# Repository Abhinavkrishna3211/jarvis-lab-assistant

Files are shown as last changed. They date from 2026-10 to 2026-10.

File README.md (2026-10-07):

# JARVIS: an offline lab assistant on the Arduino UNO Q

A voice assistant for an open IoT-club lab. Ask it where a tool is and a laser marks the hook; ask for a
component and the LED under its box lights; lend and return hardware by voice and it keeps the log.
Everything runs on the board: no internet, no cloud account.

## How it works

```
mic -> "Hey Jarvis" (App Lab keyword spotting, always listening) -> "Good evening, sir."
    -> record until you pause (6 s max) -> whisper.cpp tiny.en -> fuzzy candidate match (about 10 items)
    -> keyword rules; if they give up on a known item, Gemma 3 1B (App Lab llama.cpp runner,
       JSON-schema constrained) -> validator -> SQLite
    -> Piper reply and Bridge calls to the STM32: point / laser / box_led / ring_state
```

The model never touches facts it could invent. It returns one short JSON action; code checks the intent, the
item against the inventory, quantity, borrower and due date, and does all date and stock arithmetic.
Loans and returns are read back and need a spoken "yes" or a tap on the dashboard before anything is saved.

Why keyword rules first: on the UNO Q, Gemma 3 1B takes about 28 s per request and scored lower than the
rules on our 60 test commands (it also invents items when someone makes small talk). So the rules answer
instantly, and Gemma only gets the requests they can't parse but that mention an item or a use of one.
JARVIS says "One moment, sir" before those. The numbers are in [docs/measurements.md](docs/measurements.md).

| Layer | Where | Files |
|---|---|---|
| Intent parsing | Linux (MPU) | `python/jarvis/llm.py`, `python/jarvis/matcher.py` |
| Validation, dates, loans | Linux | `python/jarvis/validate.py`, `python/jarvis/dates.py`, `python/jarvis/db.py` |
| Dialogue / persona | Linux | `python/jarvis/dialogue.py`, `python/jarvis/engine.py` |
| Voice I/O | Linux | `python/jarvis/voice.py` |
| Laser, LEDs, servos | STM32 (MCU) | `sketch/sketch.ino` |
| Dashboard | Linux | `assets/index.html`, `python/jarvis/dashboard.py` |
| App Lab entry point | Linux | `python/main.py`, `app.yaml` |

## Our Edge Impulse models

We trained both of these ourselves in Edge Impulse. The projects are public:

| Model | What it does | Project |
|---|---|---|
| Vision | Object detection on the tool wall, trained on photos of the lab's wall | [studio.edgeimpulse.com/public/1128889](https://studio.edgeimpulse.com/public/1128889/live) |
| Keyword | The "Hey Jarvis" wake word (classes JARVIS and NOISE, about 10 ms per window), runs on the board | [studio.edgeimpulse.com/public/1128798](https://studio.edgeimpulse.com/public/1128798/live) |

The keyword model is exported as a Linux AARCH64 `.eim`, copied to `/home/arduino/.arduino-bricks/ei-models/hey-jarvis.eim`
on the board, and selected with `EI_KEYWORD_SPOTTING_MODEL` in `app.yaml`. The `.eim` files aren't committed.

## Try it without hardware

```bash
pip install -r requirements-dev.txt
python -m pytest -q              # parsing, validation and loan-logic tests
python eval/run_eval.py          # 60-command keyword baseline
python python/jarvis/app.py      # typed input, simulated hardware, dashboard on http://127.0.0.1:8000
```

The simulator uses the keyword rules alone unless you pass `--llm-url` pointing at any OpenAI-compatible
server running Gemma 3 1B; then it uses the same rules-then-Gemma parser as the board.

## Install on an Arduino UNO Q

JARVIS is a standard Arduino App Lab app. Full step-by-step instructions, including wiring, are in
[docs/tutorial.md](docs/tutorial.md). The short version:

1. Download this repository as a zip.
2. In App Lab: **My Apps → Import**, pick the zip. (Or on the board:
   `arduino-app-cli app import jarvis.zip`.)
3. Open the app. In the **Large Language Model** brick, make sure **Gemma 3 1B** is selected and
   downloaded (722 MB).
4. Plug a USB mic (and a USB speaker, or pair a Bluetooth one: see the tutorial) into a powered USB-C hub, then press **Run**. The first start downloads
   the whisper and Piper models (136 MB). After that it runs offline.
5. Say **"Hey Jarvis"** (our Edge Impulse model, see above). Without the `.eim`, remove the variable in
   `app.yaml`, set `JARVIS_WAKE_WORD=hey_arduino`, and say **"Hey Arduino"** instead.
   The dashboard is at `http://<board-ip>:7000`.

Hook angles and LED indexes in `python/jarvis/db.py` are placeholders until you calibrate in the real lab
(`docs/wiring.md`).

## Safety and privacy

- Laser: a small keychain red pointer module, driven well below its rated current, auto-off after 10 s (enforced in both Python and firmware), aimed only at the wall. Its optical power was not measured with an instrument, so the post reports it as an unverified low-power pointer.
- Camera faces the tool wall and boxes, never people. It only looks for tools (our Edge Impulse model).
- The loan log stores first names only and never leaves the board.

## Evaluation

`eval/commands.json` holds 60 labelled requests. `eval/run_eval.py` scores the keyword baseline, and with
`--gemma <url>` the Gemma pipeline, counting a request correct only if intent, item, quantity and borrower all
match after validation. On the UNO Q, with typed input:

| Parser | Correct | Time per command |
|---|---|---|
| Keyword rules | 41/60 | median 0.23 s |
| Gemma 3 1B alone | 21–22/60 | median about 28 s |
| **Hybrid (what JARVIS uses)** | **45/60** | median 0.35 s; Gemma asked on 18 of 60 |

We chose the hybrid rule after seeing Gemma's answers on these same 60 commands, so its score is optimistic.
Spoken tests with real people are still to do. All measured numbers, and how each was measured, are in
[docs/measurements.md](docs/measurements.md).

## License

MIT

## Changes after the submission deadline

The deadline was 5 Oct 2026, 12:29 PM IST. The submitted version is commit `d8290db` (pushed 5 Oct 2026,
12:24 PM IST). After the submission the code was polished and improved, and a proper schematic was added
([docs/schematic/jarvis.pdf](docs/schematic/jarvis.pdf)), which had been left out of the earlier commits.
These commits were made after the deadline:

| Commit | Time (IST) | Change |
|---|---|---|
| `bb17d30` | 6 Oct 2026, 00:34 | Two-servo pan-tilt head with camera aiming, laser moved to D7, KiCad schematic |
| `aa3d326` | 6 Oct 2026, 00:36 | Wiring guide for the pan-tilt head; README edit |
| `9af7c13` | 6 Oct 2026, 00:37 | First version of this note |
| last commit | 7 Oct 2026, 16:18 | This list; AGENTS.md intro edit |

On 6 Oct the branch was force-pushed by mistake (00:38 and 00:42 IST); on 7 Oct 2026, 16:18 IST it was restored, so every
commit up to `d8290db` is exactly as submitted.

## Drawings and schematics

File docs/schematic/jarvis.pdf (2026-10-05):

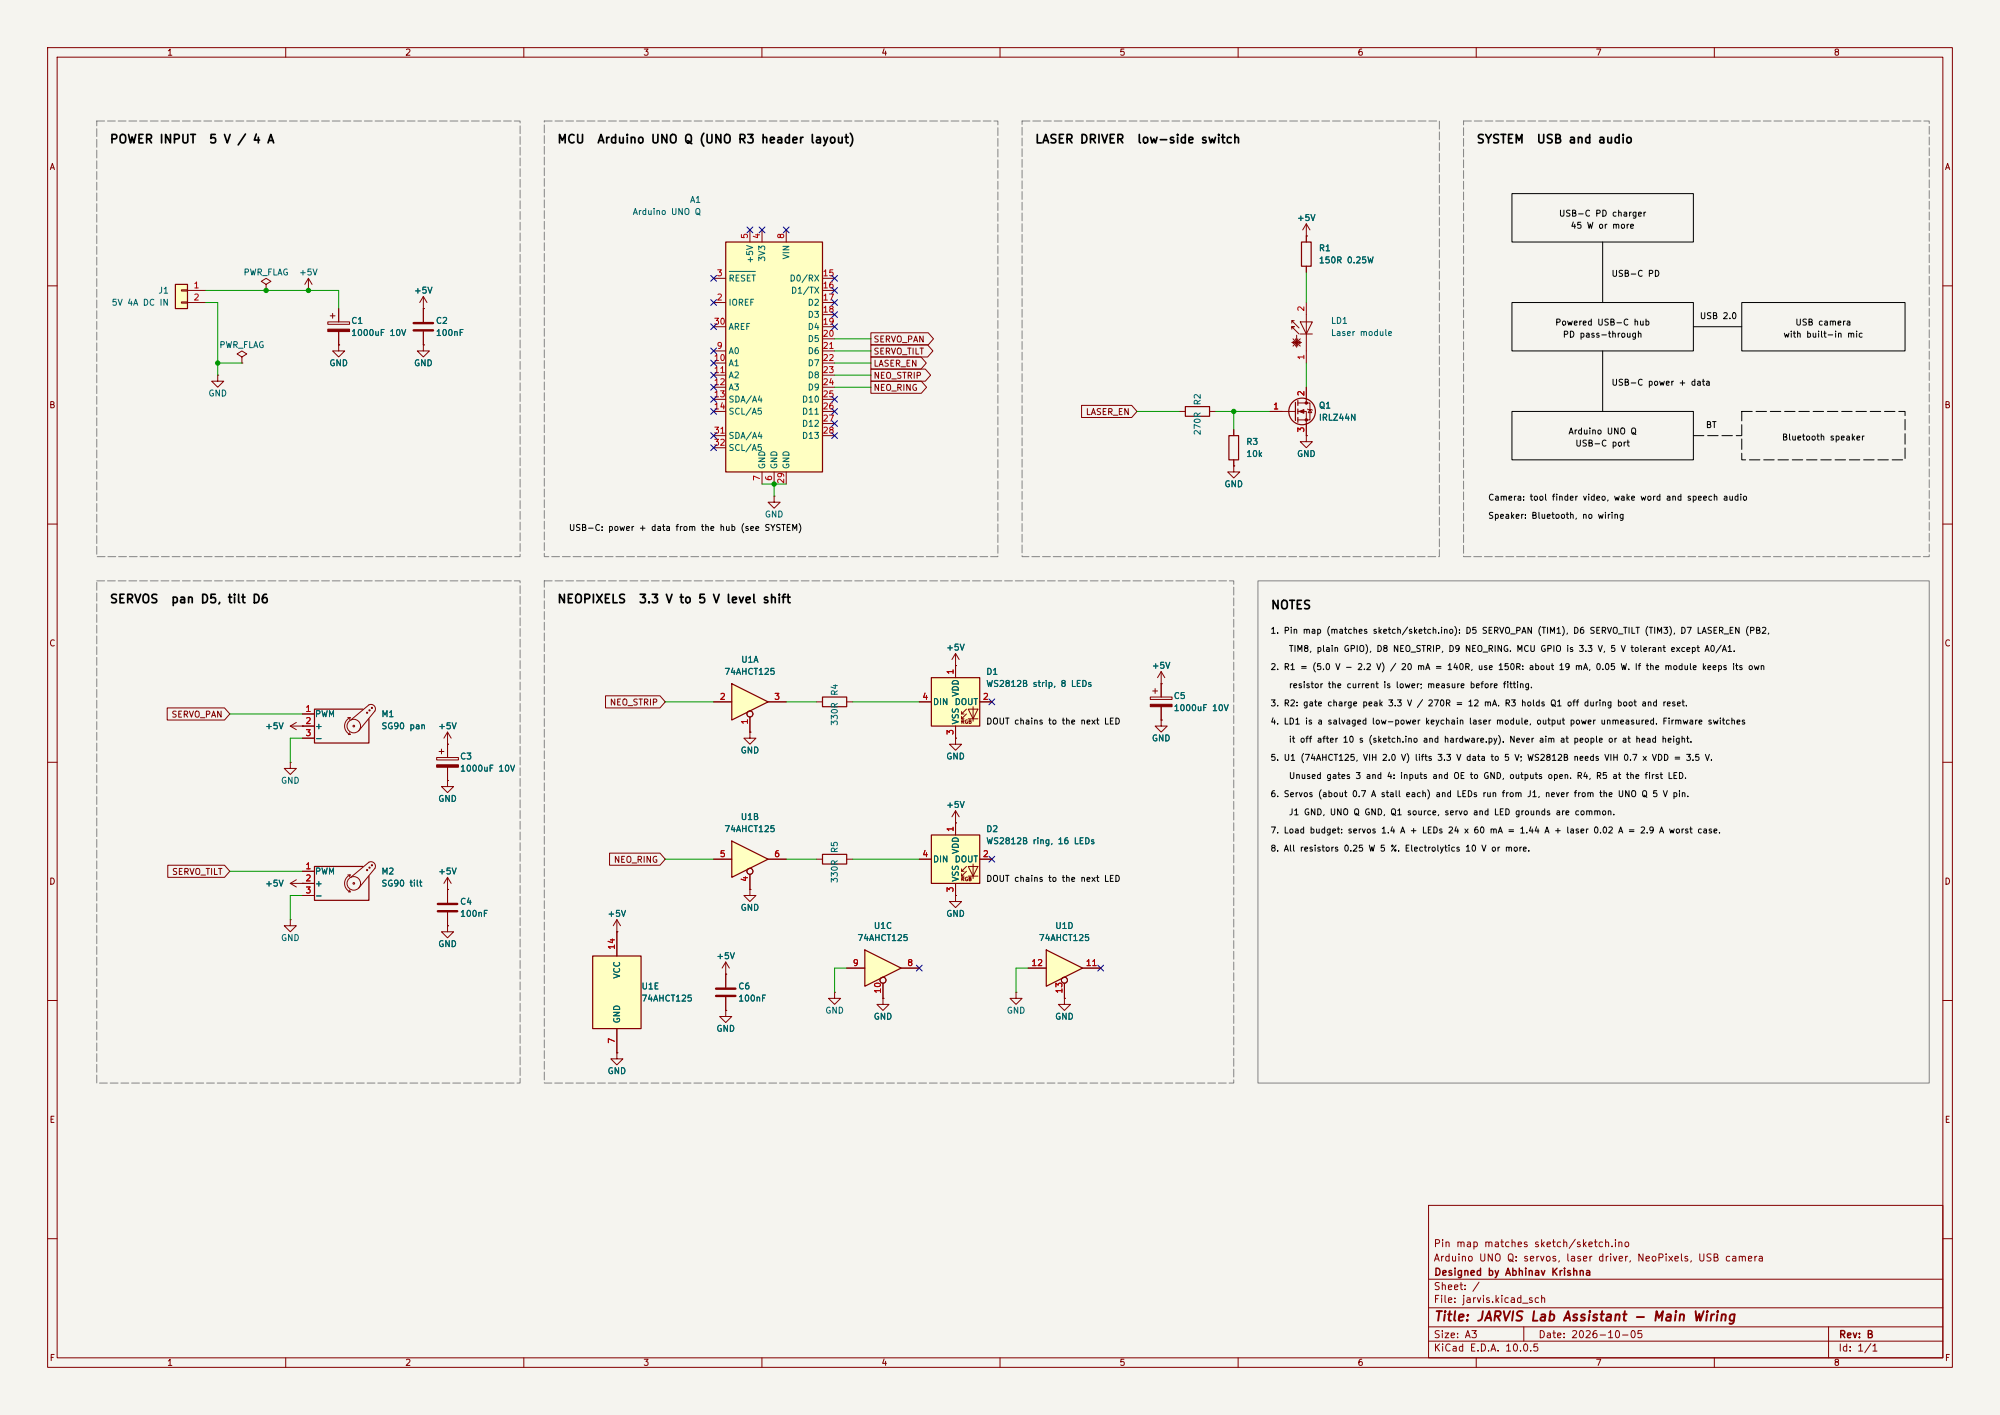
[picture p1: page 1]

Arduino UNO Q LASER DRIVER low-side switch

SYSTEM USB and audio

USB-C power + data USB-C PD USB-C: power + data from the hub (see SYSTEM)

TIM8, plain GPIO), D8 NEO_STRIP, D9 NEO_RING. MCU GPIO is 3.3 V, 5 V tolerant except A0/A1. resistor the current is lower; measure before fitting. 3. R2: gate charge peak 3.3 V / 270R = 12 mA. R3 holds Q1 off during boot and reset. 1. Pin map (matches sketch/sketch.ino): D5 SERVO_PAN (TIM1), D6 SERVO_TILT (TIM3), D7 LASER_EN (PB2, 2. R1 = (5.0 V - 2.2 V) / 20 mA = 140R, use 150R: about 19 mA, 0.05 W. If the module keeps its own 4. LD1 is a salvaged low-power keychain laser module, output power unmeasured. Firmware switches 5. U1 (74AHCT125, VIH 2.0 V) lifts 3.3 V data to 5 V; WS2812B needs VIH 0.7 x VDD = 3.5 V. 7. Load budget: servos 1.4 A + LEDs 24 x 60 mA = 1.44 A + laser 0.02 A = 2.9 A worst case. 8. All resistors 0.25 W 5 %. Electrolytics 10 V or more.

DOUT chains to the next LED

3 DIN 4 D2WS2812B ring, 16 LEDs +5V GND
RGB VDD

Designed by Abhinav Krishna
Sheet: /
File: jarvis.kicad_sch
Title: JARVIS Lab Assistant - Main Wiring

Size: A3 | Rev: B | F Date: 2026-10-05
KiCad E.D.A. 10.0.5 | Id: 1/1

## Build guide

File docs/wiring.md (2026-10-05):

# Wiring and calibration

| Part | Connects to | Notes |
|---|---|---|
| Pan servo (SG90, bottom of the pan-tilt head) | STM32 PWM pin D5 | Swings left and right; detached after each move to stop jitter |
| Laser module (from a keychain pointer, cells removed) | D7 through a logic-level MOSFET (IRLZ44N): 270 R gate, 10k gate pulldown | 5 V rail through a 150 R series resistor, about 19 mA; firmware off-timer of 10 s |
| Tilt servo (SG90, top of the head, carries the laser) | D6 | Swings up and down (lower angle = higher dot) |
| WS2812 strip (one LED per box) | D8 through a 74AHCT125 (5 V) and 330 R | 8 LEDs by default |
| NeoPixel ring (status) | D9 through the same 74AHCT125 and 330 R | 16 LEDs |
| Servos, LEDs power | Separate 5 V supply | Shared ground with the UNO Q |
| Mic, speaker | USB sound card on a powered USB-C hub | Hub also feeds the USB camera |

Full schematic with the resistor calculations: [schematic/jarvis.pdf](schematic/jarvis.pdf) (KiCad source `schematic/jarvis.kicad_sch`, regenerate with `python docs/schematic/make_sch.py docs/schematic/jarvis.kicad_sch`).

Pins are set at the top of `sketch/sketch.ino`. Servo 1.3.0 and Adafruit NeoPixel 1.15.5 compile on the
`arduino:zephyr` 1.0.0 core (verified 4 Oct 2026; versions pinned in `sketch/sketch.yaml`).

## Pan-tilt head

A standard two-SG90 pan-tilt bracket (the two-piece plastic kit).

1. Before fitting the horns, centre both servos: `POST /api/point?pan=90&tilt=90` (laser stays off).
2. Pan servo in the base, horn up; the lower bracket screws onto that horn.
3. Tilt servo in the upper bracket; the laser module sits on the tilt platform, beam parallel to it,
   held with a zip tie or hot glue so it can't slip (a slipped laser silently breaks the calibration).
4. Mount the head at bench height facing the tool wall, with no walkway between head and wall. The beam
   should only ever reach the wall, never head height.
5. Fix the camera next to the head, not on it, so the camera's view and the head don't move together.
   Moving either one means calibrating again.
6. Servo power comes from the separate 5 V supply (about 0.7 A stall each), never from the UNO Q's 5 V pin.

## Calibrating hooks

Two steps, both from the dashboard host (`http://<board-ip>:7000`):

1. **Hook angles by hand.** For each hook, jog until the dot sits on it:
   `POST /api/point?pan=90&tilt=65&laser=1` (the laser still switches off after 10 s). Write each
   hook's `(pan, tilt)` into `HOOK_ANGLES` in `python/jarvis/db.py` and restart the app. Record the miss
   distance in centimetres for the evaluation.
2. **Camera fit.** Hang every tool on its own hook, then `POST /api/calibrate`. The camera finds each tool
   with the vision model and fits pixel position to `(pan, tilt)`; the result is saved to `data/vision.json`.
   It needs 2 or more tools seen. Hooks in one column only teach tilt; hooks spread across the wall teach
   both axes. Every aim is clamped to the box the calibrated hooks span, so a bad detection can't swing
   the laser off the wall.

Without `vision.json` (or with the camera unplugged), JARVIS points at each tool's home hook.

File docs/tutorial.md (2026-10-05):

# Build your own JARVIS: step by step

This guide takes you from an empty Arduino UNO Q to a lab assistant that answers to its wake word, marks
tools with a laser, and keeps the lending log by voice. The steps are the ones we actually followed; any
step not yet run on real hardware is marked **(not yet verified)**.

Numbers quoted here come from [measurements.md](measurements.md).

## What you need

| Part | Why | Status on our bench |
|---|---|---|
| Arduino UNO Q (2 GB is enough) | Runs everything: Linux for speech and the model, STM32 for the hardware | ✅ |
| Powered USB-C hub with USB-A ports | The UNO Q has one USB-C port; mic, speaker and power share it | to buy |
| USB microphone (a USB webcam's mic works) | Voice in | ✅ Arducam camera mic |
| Speaker: USB, or a Bluetooth speaker (see Step 5) | Voice out | ✅ Bluetooth |
| SG90 servos × 2 and a pan-tilt bracket | Aim the laser | 1 of 2 servos |
| Laser module from a keychain pointer (cells removed), plus a logic-level MOSFET (IRLZ44N) | Marks the hook on the tool wall | ✅ both |
| WS2812 LED strip | One LED under each component box | to buy |
| 16-LED NeoPixel ring | Status: idle, listening, thinking, speaking, error | ✅ |
| Separate 5 V supply | Servos and LEDs draw too much for the board | |

You also need a computer with [Arduino App Lab](https://www.arduino.cc/en/software/) and an
internet connection **for the first start only** (to download the models).

## Step 1: Prepare the board

1. Connect the UNO Q to Wi-Fi through App Lab's first-run setup.
2. Check you have room. Open the board's terminal (App Lab, or `ssh arduino@<board-ip>`) and run:
   ```bash
   free -m      # we had 1249–1277 MB available out of 1740 MB
   df -h /      # we had 1.1 GB free out of 9.8 GB: too little
   ```
   JARVIS needs about 2.5 GB of free disk on the first start: the Gemma model (722 MB), the
   llama.cpp and keyword-spotting runner images, and the speech models (136 MB). If you're short, export
   any old apps you want to keep (`arduino-app-cli app export <app> backup.zip --include-data`), then delete
   them in App Lab and remove Docker images you no longer use (`docker images`, then `docker rmi <image>`).

## Step 2: Import the app

1. Download this repository as a zip (GitHub: **Code → Download ZIP**).
2. In App Lab, import the zip as a new app. You can do the same from the board's terminal:
   ```bash
   arduino-app-cli app import jarvis.zip
   ```
   Verified on our UNO Q 2GB.

What's inside, and why App Lab needs each piece:

| Path | Role |
|---|---|
| `app.yaml` | Declares the app and its three bricks: `arduino:llm` (Gemma 3 1B), `arduino:web_ui` (dashboard), `arduino:keyword_spotting` (wake word) |
| `python/main.py` | Entry point App Lab runs. Ends with `App.run()` |
| `python/jarvis/` | The assistant: matcher, validator, dates, loans database, persona, speech |
| `python/requirements.txt` | `pywhispercpp` and `piper-tts`, installed automatically by App Lab |
| `assets/index.html` | Dashboard, served on port 7000 |
| `sketch/` | STM32 firmware: servos, laser off-timer, LED strip and ring |

## Step 3: Choose the model

Open the app and click the **Large Language Model** brick. Select **Gemma 3 1B**
(`llamacpp:gemma-3-1b-it-Q4_0`, 722 MB) and download it. App Lab runs it in its own llama.cpp container.
Nothing has to be compiled. From the board's terminal the same install is:
```bash
curl -X PUT http://127.0.0.1:8800/v1/models/llamacpp:gemma-3-1b-it-Q4_0
```
The download took 7 min 37 s for us. Keep the board close to the router: ours dropped off Wi-Fi at 34%
signal halfway through and didn't reconnect until we power-cycled it.

Why Gemma 3 1B: it's the largest instruction-tuned model App Lab offers for the UNO Q, and JARVIS only
asks it for one short JSON action per request. The code checks everything it returns.

On the UNO Q it takes about 28 s per request, so JARVIS tries simple keyword rules first and only asks
Gemma when they give up on a request that mentions a known item. See
[measurements.md](measurements.md) for how it did.

## Step 4: Wire the hardware

See [wiring.md](wiring.md) for the pin table. In short: servos on D5/D6, laser through the MOSFET on D7,
LED strip on D8, status ring on D9, all powered from a separate 5 V supply with a shared ground.

**Laser safety:** the keychain pointer's output power is unmeasured, so it is run current-limited (about 20 mA) and treated as a hazard to eyes. The firmware switches it off after 10 s no matter
what Python asks for, and Python caps the request at 10 s too. Mount the turret so it can only reach
the tool wall, never head height.

**Pan-tilt head and calibration:** build the head and calibrate it as in [wiring.md](wiring.md)
(Pan-tilt head, then Calibrating hooks): jog each hook's angles with `/api/point`, then let the camera fit
pixels to angles with `/api/calibrate`.

The firmware compiles as-is for the UNO Q: 12% of flash, 15% of RAM. App Lab flashes it when you press Run.

## Step 5: Run it

Plug in the USB mic first: App Lab refuses to start the app without one
("No Microphone Device Found"), because the wake-word brick needs it. Press **Run** in App Lab. On the first start, the app downloads the whisper tiny.en (75 MB) and Piper
voice (61 MB) models into the app's `data/` folder. That took 144 s on our Wi-Fi. After that, everything
works offline. The app starts on our board with the camera mic and the wake-word brick.
The status ring shows one solid colour per state: dim blue idle, bright blue listening, amber thinking,
white speaking, red error. It isn't animated, because constant redraws blocked the Bridge.

Speak from arm's length: right next to the mic the input clips and whisper repeats words. JARVIS stops
recording about 0.8 s after you stop talking (6 s at most).

**Start on boot.** App Lab only restarts the default app after a power cut:
`arduino-app-cli properties set default user:jarvis` (we hit this after a power cycle).

**Mic recovery.** After a USB mic or camera is replugged, PipeWire can lose it until WirePlumber restarts.
`tools/mic-watch.sh` checks for that and restarts WirePlumber and the app. Run it every minute from your
crontab (`crontab -e`, add `* * * * * $HOME/ArduinoApps/jarvis/tools/mic-watch.sh`).

**Bluetooth speaker (optional).** Pair it once on the board (`bluetoothctl`: `power on`, `scan on`,
`pair <MAC>`, `trust <MAC>`, `connect <MAC>`). On a headless board, WirePlumber needs
`monitor.bluez.seat-monitoring = disabled` in `~/.config/wireplumber/wireplumber.conf.d/80-bluez-headless.conf`;
if the login screen's audio session still holds Bluetooth, disable bluez there too (needs root). The app finds the
Bluetooth sink by itself when no USB speaker is plugged in. Bluetooth shares the radio with 2.4 GHz Wi-Fi, so we
also ran `nmcli connection modify <wifi> connection.autoconnect-retries 0` so the board keeps reconnecting.

- Dashboard: `http://<board-ip>:7000`. Stock, open loans, tap-to-confirm, a text box, and a Talk button.
- Wake word: say **"Hey Jarvis"** (our Edge Impulse model, Step 7), or "Hey Arduino" with App Lab's built-in one.

## Step 6: Talk to it

```
You:    Hey Jarvis
JARVIS: Good afternoon, sir. How may I help?
You:    Where is the multimeter?
JARVIS: The multimeter is on hook 3, sir. I've highlighted it for you. Anything else?   (laser, off after 10 s)
You:    No, thank you.
JARVIS: Very well, sir. I'll be here if you need me.

You:    Hey Jarvis
JARVIS: Good evening, sir. The lab is at your disposal.
You:    Lend two ESP32s to Arjun till Friday.
JARVIS: Lending 2 ESP32 to Arjun until Friday 9 October. Shall I log it?
You:    Yes.
JARVIS: Logged. I'll keep an eye on its return.
```

Nothing is saved until you say yes (or tap **Yes, log it** on the dashboard).

## Step 7: Train "Hey Jarvis"

Uses App Lab's Edge Impulse integration: record the wake word in many voices plus lab noise, train a
keyword model (ours: MFE plus a small classifier, classes JARVIS and NOISE), save it as `models/hey-jarvis.eim`
and point `app.yaml` at it. Ours only knows JARVIS and NOISE, so other speech can wake it; an "other
speech" class is the next retrain.

## Step 8: Your lab's inventory (not yet done)

Replace the placeholder items, hook angles and LED indexes in `python/jarvis/db.py`. Calibrate each hook as in
[wiring.md](wiring.md) (Calibrating hooks).

## Try it on a laptop first

No board needed:
```bash
pip install -r requirements-dev.txt
python -m pytest -q
python python/jarvis/app.py
```

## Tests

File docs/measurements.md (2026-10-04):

# Measurements

Every number here comes from a real run on the bench. Each entry says what was measured, how, and
whether the input was typed, spoken by a person, or synthesized. If something didn't work, it stays in.

## Test bench

| | |
|---|---|
| Board | Arduino UNO Q, 2 GB RAM (Qualcomm QRB2210, 4 × Cortex-A53 @ 2.0 GHz per spec; STM32U585 MCU) |
| OS | Debian, kernel 6.16.7; Arduino App Lab CLI and daemon 0.13.0 |
| Python runtime | App Lab container `python-apps-base:0.12.0`, Python 3.13 |
| Memory at idle | 1740 MB total, 1249–1277 MB available (`free -m`, App Lab running, desktop on) |
| Disk | 9.8 GB root, 90% used before cleanup, 62% after, 70% with Gemma installed (`df -h /`) |
| Network | Wi-Fi, 34–49% signal on 2.4 GHz at the bench |

## 1. Firmware compiles on the UNO Q core (4 Oct 2026)

**What:** does `sketch/sketch.ino` (servo, laser timer, NeoPixel strip and ring, four Bridge calls)
build for the UNO Q's Zephyr-based core with the libraries pinned in `sketch/sketch.yaml`?

**How:** on the board, `arduino-cli compile --fqbn arduino:zephyr:unoq --profile default sketch`.
Nothing was flashed.

**Result:** builds. 102,288 bytes of 786,432 flash (13%), 41,280 bytes of 262,144 RAM (15%).

**Rebuilt after the ring fix (section 6), same command:** 101,716 bytes flash (12%), 40,940 bytes RAM
(15%), 1 min 28 s to compile on the board.

**Gotcha:** the first build failed with `Arduino_RPClite.h: No such file`. Sketch profiles don't
pull library dependencies automatically, so every dependency of Arduino_RouterBridge has to be listed.

## 2. Speech-to-text and text-to-speech on the UNO Q CPU (4 Oct 2026)

**Why these engines:** App Lab's own speech blocks (`arduino:asr`, `arduino:tts`) only run on the
VENTUNO Q. On the UNO Q we use whisper.cpp (`pywhispercpp` 1.5.1) and Piper (`piper-tts` 1.8.0).
Both install as prebuilt ARM wheels inside the App Lab container, with nothing to compile.

**How:** a throwaway App Lab container on the board. Piper speaks a sentence, the audio is resampled
from 22,050 Hz to 16 kHz, and whisper transcribes it. Timings use `time.time()` around each call,
after one warm-up call. **The input is synthesized speech (Piper's northern English male voice),
not a person.** Piper's pronunciation of "ESP32s" is itself poor, so treat accuracy as a lower bound
on the pipeline, not a measure of how it does with real students.

### Text to speech (Piper `en_GB-northern_english_male-medium`)

| Sentence | Audio length | Time to synthesize |
|---|---|---|
| "Good evening, sir. What do you need?" | 2.0 s | 1.00 s |
| "Where is the wire stripper" | 1.4 s | 0.74 s |
| "Lend two ESP32s to Arjun till Friday" | 2.7 s | 1.42 s |

That's about 0.5 s of work per second of speech, so Piper is not the bottleneck.

### Speech to text (whisper tiny.en): four settings tried

| Setting | Time per command | "wire stripper" | "Lend two ESP32s to Arjun till Friday" | "What is overdue" |
|---|---|---|---|---|
| tiny.en, defaults (30 s window) | 4.8–7.0 s | "Y stripper" | "Len Tujas Betha he twos to Arjantil Friday." | "What is over to you?" |
| + hint list of items/names | 5.3–5.5 s | correct | garbled | "What is over to you?" |
| + hint list + `audio_ctx=512` | 1.7–3.1 s | "Y stripper" | garbled | "What is over to you?" |
| base.en + hint list + `audio_ctx=512` | 3.8–4.1 s | correct | garbled | correct |
| **tiny.en + `audio_ctx=512` (chosen)** | **1.40–2.33 s** | "Y stripper" | "lent to the SB 32 to Argentina till Friday." | "What is over to you?" |
| tiny.en + `audio_ctx=768` | 2.18–2.27 s | same as 512 | same as 512 | same as 512 |

**What we learned:**
- whisper pads every clip to a 30 s window by default. `audio_ctx=512` shrinks that to about 10 s
  and cuts the time by a factor of 3.4 (4.8 s → 1.4 s) with the same transcripts. Our recordings are
  5 s, so nothing gets cut off.
- **The hint list is harmful.** On a short clip, whisper output the hint itself
  ("Arjun returned the multimeter" came back as "Arjun, Meera."). We dropped it.
- base.en is more accurate ("overdue", "wire stripper") but 2.7 times slower. We'll decide between tiny
  and base once we have recordings of real voices.

**Memory:** Piper + whisper tiny.en loaded together peaked at 381 MB RSS.
**Disk:** whisper tiny.en model 75 MB, Piper voice 61 MB. Both are downloaded once on first start.

## 3. Installing and starting the app on the board (4 Oct 2026)

**How:** board cleaned first (two old apps exported to zips and deleted, three unused Docker images
removed): disk went from 90% to 62% used. Then `arduino-app-cli app import`, the model download, and
`arduino-app-cli app start user:jarvis`, timed with `time`.

| Step | Result |
|---|---|
| Gemma 3 1B download (722 MB, through the App Lab daemon) | 7 min 37 s on our Wi-Fi (about 1.6 MB/s); disk 62% → 70% |
| First `app start`: compile and flash the sketch | about 2 min 14 s |
| First `app start`: pull llama.cpp runner image, create containers | 52.6 s |
| First run: install `pywhispercpp` + `piper-tts`, download speech models | about 1 min |
| Dashboard reachable at `http://<board-ip>:7000` | yes |

**What went wrong, and what it tells you:**
- **The first download attempt killed the Wi-Fi.** The board was at 34% signal. About 45 s into the
  722 MB download the link timed out and NetworkManager never reconnected, so the board needed a
  power cycle. At 42–49% signal the retry finished. Put the board near the router for the first start.
- **The app won't start without a microphone** if `app.yaml` declares the wake-word brick
  (`[ERROR] No Microphone Device Found`). Our bench has no mic yet, so for these measurements the
  brick was removed from the board's copy of `app.yaml` only. Even then, the app's wake-word setup
  retried the missing service for 2 min 14 s before falling back to the dashboard Talk button.
- One start failed on a DNS lookup for `ghcr.io` right after a Wi-Fi reconnect. Retrying worked.

## 4. Gemma 3 1B speed on the UNO Q (4 Oct 2026)

**How:** a script inside the app container sends JARVIS's real prompt (instructions + up to 10
candidate items + the request, 185–214 tokens) to App Lab's llama.cpp runner, exactly as the app
does, and records wall time plus llama.cpp's own `timings`. **Input is typed text.** One cold
request, then six different requests. Memory sampled every 3 s with `docker stats` and `free -m`.
Runner settings come from App Lab: 4 threads, context 16,384, batch 512.

| | Result |
|---|---|
| Reading the prompt | 9.3–10.4 tokens/s |
| Generating the reply | 4.7–5.1 tokens/s (one run: 2.5) |
| Time per command, warm | **26.6–35.2 s** (prompt about 21 s, reply of 37–58 tokens about 8 s) |
| First command after start (model load) | 46.6 s |
| Memory, llama.cpp runner | up to 869 MB |
| Memory, JARVIS app with whisper + Piper loaded | up to 233 MB |
| Lowest `available` memory during the run | 721 MB of 1740 MB |
| CPU clock during the run | 1.61 GHz on all four cores (`scaling_cur_freq`), 53 °C |

**What we learned:**
- **Memory is fine; speed is the problem.** Everything fits in 2 GB with about 700 MB to spare, but
  about 30 s per command is far too slow to talk to.
- **The fixed part of the prompt isn't reused.** Sending the same request twice still processed all
  211 tokens, even with `cache_prompt` set. App Lab runs llama.cpp in its experimental router mode.
- **Our 30 s client timeout was shorter than a real request.** Raised to 90 s.
- Gemma's replies were often wrong on this sample: "lend two ESP32s to Arjun till Friday" and
  "Meera returned the soldering iron" both came back as `FIND_TOOL`, and it filled in fields that
  don't apply (`"due": "in 3 days"` on a tool search). The validator throws those extra fields away,
  but the wrong intent gets through. Section 5 has the full 60-command comparison.

## 5. Gemma vs the keyword baseline, 60 typed commands (4 Oct 2026)

**How:** `eval/run_eval.py --gemma http://llamacpp-models-runner:9999/v1`, run inside the app
container on the board. **Typed input.** Both parsers go through the same validator, and a command
counts as correct only if intent, item, quantity and borrower all match what the system would act on.
Gemma uses the prompt in `python/jarvis/llm.py` as of this date (zero-shot, JSON-schema constrained,
temperature 0). Raw results: one row per command, saved by `--json`.

| Intent | Commands | Keyword baseline | Gemma 3 1B |
|---|---|---|---|
| FIND_TOOL | 9 | 5 | **9** |
| FIND_COMPONENT | 8 | 6 | **8** |
| TOOL_FOR_TASK | 8 | 0 | 0 |
| LEND | 8 | **4** | 0 |
| RETURN | 6 | **6** | 0 |
| WHO_HAS | 5 | **4** | 0 |
| STOCK | 4 | **4** | 0 |
| OVERDUE | 4 | **4** | 1 |
| UNKNOWN (off-topic) | 8 | **7** | 4 |
| **Total** | **60** | **40** | **22** |

Per command: both right 15, keyword only 25, Gemma only 7, neither 13.

**What we learned:**
- **Gemma loses, 22 to 40.** It is better at one thing, recognising an item from loose wording ("i
  can't find the glue gun", "got any ultrasonic sensors"), and that accounts for all 7 commands
  only Gemma got right.
- **It labels almost everything as a search.** Every loan, return, stock and who-has question came
  back as `FIND_TOOL` or `FIND_COMPONENT`, usually with the right item. With this prompt, the 1B
  model picks up the item but not the intent.
- **Tool-for-task: right tool, wrong label.** For 6 of 8 "what do I use to…" questions Gemma named
  the right tool (side cutters for zip ties, multimeter for continuity) but labelled it `FIND_TOOL`,
  so the scorer counts it wrong. JARVIS would still point at the right hook. The keyword baseline
  named none of them. We report this separately rather than re-score.
- **It makes things up for off-topic requests.** "What's the weather", "play some music" → the
  multimeter; "thanks jarvis" → the ultrasonic sensor. The validator can't catch these because the
  item is real. The keyword baseline correctly said it didn't understand.
- **What-if, computed from the same recorded answers:** keyword parser first, Gemma only when the
  keyword parser gives up, would score 41/60 and call Gemma on 25 of 60 commands.
- **Timing:** a stray second copy of the evaluation shared the model for the first 34 commands, so
  only the last 26 timings are clean: **23.1–32.5 s, median 28.0 s**, matching section 4.

## 7. Second run, and the hybrid parser JARVIS now uses (4 Oct 2026)

Because of section 5, `python/jarvis/llm.py` now has `HybridLLM`: the keyword rules answer first, and Gemma
is asked only when the rules return UNKNOWN **and** the request names an item or a known use of one
(matcher score 0.7 or more). JARVIS says "One moment, sir. Let me think." before a Gemma call.

**Be aware:** we chose this rule after seeing section 5's answers, on the same 60 commands, so the hybrid
score below is optimistic. A fresh set of commands would be a fairer test.

**How:** same as section 5, a clean single run, typed input, board otherwise idle. Then the matcher bug
below was fixed and the keyword and hybrid parts were run again (`eval_v3`).

| Intent | Commands | Keyword (old matcher) | Gemma 3 1B (2nd run) | Keyword (fixed matcher) | **Hybrid (fixed matcher)** |
|---|---|---|---|---|---|
| FIND_TOOL | 9 | 5 | 9 | 5 | 8 |
| FIND_COMPONENT | 8 | 6 | 8 | 6 | 8 |
| TOOL_FOR_TASK | 8 | 0 | 0 | 0 | 0 |
| LEND | 8 | 4 | 0 | 4 | 4 |
| RETURN | 6 | 6 | 0 | 6 | 6 |
| WHO_HAS | 5 | 4 | 0 | 4 | 4 |
| STOCK | 4 | 4 | 0 | 4 | 4 |
| OVERDUE | 4 | 4 | 1 | 4 | 4 |
| UNKNOWN (off-topic) | 8 | 7 | 3 | 8 | 7 |
| **Total** | **60** | **40** | **21** | **41** | **45** |
| Time per command | | median 0.23 s | median 28.8 s (max 37.6) | median 0.23 s | **median 0.35 s, mean 8.5 s, max 33.4 s** |

The hybrid called Gemma on 18 of 60 commands.

**What we learned:**
- **Gemma isn't fully repeatable at temperature 0.** The second run gave a different answer on 2 of 60
  commands (21 instead of 22). "how do i program a pico" went from UNKNOWN to "soldering iron".
- **Matcher bug found and fixed.** Three-letter aliases ("esp", "uno") fuzzy-matched any two-letter
  fragment at 0.76: the "es" in "yes", the "un" in "Arjun". So "lend a teleporter to Arjun till Friday"
  became an ESP32 loan (still behind the spoken yes), and a stray "yes" was sent to Gemma. Short aliases
  now have to match exactly. Keyword baseline 40 → 41; regression test added.
- **When Gemma is wrong in the hybrid, it's mostly harmless.** Of the 13 hybrid misses that went to
  Gemma, 12 came back as a search (`FIND_TOOL`/`FIND_COMPONENT`), and 6 of those name the right tool for a
  "what do I use to…" question, so the laser would still mark the right hook. None became a loan or
  a return. The worst is "how do i program a pico", which points at the soldering iron.
- **Still not solved:** loans phrased without "lend/give/loan" ("Rahul needs three servos until
  Monday", "Nikhil is taking the soldering iron") get treated as searches.

## 8. Full voice pipeline on the board, synthesized speech (4 Oct 2026)

**How:** `bench_pipeline.py` inside the app container. **Synthesized input:** Piper speaks the request,
it's resampled to 16 kHz and padded to the app's 5 s recording, then whisper tiny.en → engine
(`HybridLLM` with the real Gemma, real `BridgeHardware` to the flashed sketch, fresh database) → Piper
speaks the reply. No mic or speaker; nothing wired to the pins. Second run, after the matcher fix.

| Said (by Piper) | Whisper heard | Path | Speech to text | Engine | Text to speech |
|---|---|---|---|---|---|
| where is the wire stripper | Where is the wire stripper? | rules | 1.59 s | 0.35 s (Bridge 45 ms) | 1.53 s |
| show me the tweezers | Show me the tweezers. | Gemma | 1.55 s | 66.3 s * | 1.79 s |
| lend two ESP32s to Arjun till Friday | Learn to USB for E2s to Argentina till Friday. | Gemma | 6.97 s * | 57.4 s * | 1.45 s |
| yes (nothing pending) | Yes. | rules | 2.08 s | 0.02 s | 1.81 s |
| what's the weather | What's the weather? | rules | 1.56 s | 0.12 s | 0.69 s |

Loading whisper and Piper takes 12.8 s at app start.

**Time from the end of a request to the start of the reply** (the 5 s recording comes first):
**about 3.5 s** when the rules handle it. When Gemma handles it, about 3.5 s plus the Gemma time, which is
24–34 s in sections 5 and 7.

\* **Why these are slow, and why we don't count them:** the benchmark loads its own whisper and Piper
next to the running app's copy, so the board held two sets of speech models. During the Gemma call:
570 MB available, `jarvis-main-1` 300 MB, `jarvis-llamacpp-models-runner-1` 479 MB (it had been 869 MB),
so the model weights were being pushed out of memory and re-read. In the first pipeline run, before the
matcher fix, the same Gemma calls took 31.6–39.6 s. The evaluation in section 7 ran in the same container
without loading speech models, which matches how the app really runs.

**Memory as the app really runs:** app with speech models loaded about 300 MB, Gemma runner 869 MB,
about 1.17 GB of 1.74 GB, which fits.

**What we learned:**
- Whisper tiny.en gets short, plain requests right, but it wrecked the loan sentence ("ESP32s to
  Arjun" → "USB for E2s to Argentina"). The first run heard "Lentivius B32s to Argentina Friday". This is
  Piper's voice, not a person; real spoken tests are still needed. Names and part numbers are the weak spot.
- Bridge calls inside a real command take 39–66 ms in total, since one command makes several calls.

## 6. Bridge calls from Linux to the sketch (4 Oct 2026)

**How:** inside the app container, `Bridge.call()` for each of `ring_state`, `box_led`, `point`,
`laser(False)`, 20 times each after one warm-up, timed with `time.perf_counter()`. Sketch flashed by
`app start`. Nothing is wired to the pins yet, so this measures the link, not the servos.

| Sketch version | Result |
|---|---|
| Status ring animated, redrawn every 40 ms | **every call timed out after 10 s** (two attempts) |
| Same sketch, ring redraw commented out | all four calls work: 5.9–7.9 ms |
| **Fixed: ring drawn once per state change, solid colour per state** | **6.2–8.2 ms** (median 6.9–7.6 ms) |

**What we learned:** the ring animation called `ring.show()` 25 times a second. Each call bit-bangs
the NeoPixel data and holds up the MCU, and the Bridge never got a reply out in time. The LED strip
under the boxes, which only redraws when asked, was never a problem. So the ring now shows a solid
colour per state (dim blue idle, bright blue listening, amber thinking, white speaking, red error),
drawn only when the state changes. The router log also shows `invalid packet, expected array`
right after every flash, with or without the fix; that's harmless noise while the MCU restarts.

**Not verified yet:** that the laser actually switches off after 10 s and that the servos reach their
angles. Both need the parts on the bench.

## 9. First real spoken commands, full app running (4 Oct 2026)

**How:** the full app as App Lab runs it, all three bricks (Gemma, dashboard, wake word). **Spoken by a
person**, about 1 m from the Arducam B0490 USB camera, using its built-in microphone (the camera reports a
"Microphone" input; the BOYA BY-M1 lapel mic's jack-to-USB adapter failed to enumerate on the hub). No speaker
attached, so the replies were read from the app log. Mic gain at 100%.

| Try | Wake word | Whisper heard | Result |
|---|---|---|---|
| 1 | detected | "Hey, I already know. Hey, I already know. Hey, I already know." | "didn't catch that" |
| 2 | detected | "Hey Aradino, hey Aradino." | Gemma (48.9 s): "6 Arduino Uno available" |
| 3 | detected | (empty, three times) | asked to repeat |
| 4 | detected | **"Where is the wise triple?"** (peak level 31,810 of 32,767) | **Gemma (40.8 s): "Marked. Do return the wire stripper to the same hook, sir."** ✅ |

Timings in try 4: greeting synthesis 2.3 s, whisper 1.85 s, Gemma 40.8 s.

**What we learned:**
- **The wake word works with the camera mic.** It triggered on all four tries; we didn't count misses or false wakes.
- **Without a speaker, people don't know when to talk.** In tries 1–3 the speaker kept repeating the wake
  word or spoke before recording began. A speaker, or the status ring, is needed for real use.
- **The wake word itself gets transcribed and matched.** "Hey Aradino" is close to the Arduino Uno's alias
  "arduino", so it went to Gemma and lit a box. Training "Hey Jarvis" removes the clash.
- **The hybrid did its job on try 4.** Whisper turned "wire stripper" into "wise triple", the keyword rules
  gave up, and Gemma recovered the right tool.
- **Gemma is slower with everything running:** 40.8 and 48.9 s here vs 24–34 s in sections 5 and 7, now that the
  wake-word runner shares the CPU and memory. Two samples only.
- The mic is close to clipping at 100% gain with a person at 1 m; we'll lower it if clipping shows up.

## 10. Spoken conversations with a Bluetooth speaker (4 Oct 2026)

**How:** full app, all three bricks. **Spoken by a person** into the Arducam camera mic (gain 256 of 256).
Replies played on a UBON MINI STAR SP 25 Bluetooth speaker. Timings from the app log.

| Time | Distance | Mic peak | Whisper heard | Whisper | Engine | Reply synth |
|---|---|---|---|---|---|---|
| 12:15 | close | 32,767 (clipped) | "Where is the micimeter?" repeated | 3.94 s | 1.61 s | 1.96 s |
| 13:03 | close | 32,767 (clipped) | repeated phrase | 3.96 s | 2.08 s | n/a |
| 13:05 | arm's length | 17,244 | "Where is the multimeter?" | 1.69 s | 0.31 s | 2.30 s |
| later | arm's length | 20,473 | "where is the multimeter?" | 1.72 s | 0.30 s | 3.48 s |
|  | (follow-up) | 29,408 | "No, thank you." | 1.66 s | 0.01 s | 1.60 s |

The last two rows are one conversation: "Good afternoon, sir. How may I help?" → "The multimeter is on hook 3,
sir. I've highlighted it for you. Anything else?" → "No, thank you." → "Very well, sir. I'll be here if you
need me." The keyword rules handled both turns; Gemma wasn't needed.

**What we learned:**
- **Distance matters more than gain.** Close to the mic the input clips and whisper repeats phrases (3.9 s
  instead of 1.7 s). At arm's length transcripts were exact.
- **About 4 s from end of speech to the reply starting** (5 s recording window not counted), plus Bluetooth delay.
- **Bluetooth works but costs effort:** App Lab's Speaker doesn't pick a Bluetooth sink on its own (we pass the
  PipeWire node), `play_pcm` returns about 0.2 s before the sound ends, and the login screen's audio session
  grabbed Bluetooth until we disabled it there (needs root).
- **Bluetooth hurts Wi-Fi on this board** (shared 2.4 GHz radio): ping 115–167 ms and one full drop that needed a
  power cycle. We set NetworkManager to retry forever.
- Voice: Piper `en_GB-northern_english_male-medium` at normal speed, picked by ear over `alan` and `semaine`.

## Still to measure
- A fresh set of commands to test the hybrid rule fairly (section 7).
- Spoken commands from real people (needs a USB mic), wake word false wakes per hour and misses
  out of 50, laser pointing error (needs the servo and laser).

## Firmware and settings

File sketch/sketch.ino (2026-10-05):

// JARVIS: STM32 side. Exposes four calls to the Linux side over the Bridge:
//   point(pan, tilt), laser(on, seconds), box_led(index, colour), ring_state(state)
// The MCU only moves hardware; every decision is made and validated on the Linux side.
#include <Arduino_RouterBridge.h>
#include <Servo.h>
#include <Adafruit_NeoPixel.h>

// Pin map: adjust to your wiring (see docs/wiring.md and docs/schematic/jarvis.pdf).
// Laser on D7 (PB2): plain GPIO on TIM8, which no servo or NeoPixel pin uses. D3 shared TIM3 with D6/D8
// and doubles as the OPAMP2 output.
const int PAN_PIN = 5, TILT_PIN = 6, LASER_PIN = 7, STRIP_PIN = 8, RING_PIN = 9;
const int STRIP_LEDS = 8, RING_LEDS = 16;
const unsigned long LASER_MAX_MS = 10000;  // hard safety limit, enforced here as well

Servo pan, tilt;
Adafruit_NeoPixel strip(STRIP_LEDS, STRIP_PIN, NEO_GRB + NEO_KHZ800);
Adafruit_NeoPixel ring(RING_LEDS, RING_PIN, NEO_GRB + NEO_KHZ800);

unsigned long laserOffAt = 0, servoDetachAt = 0, boxOffAt = 0;
String ringMode = "idle";
bool ringDirty = true;

uint32_t colourOf(const String& c, Adafruit_NeoPixel& s) {
  if (c == "red")   return s.Color(255, 0, 0);
  if (c == "amber") return s.Color(255, 140, 0);
  if (c == "blue")  return s.Color(0, 90, 255);
  return s.Color(255, 255, 255);
}

void point(int p, int t) {
  pan.attach(PAN_PIN); tilt.attach(TILT_PIN);
  pan.write(constrain(p, 0, 180)); tilt.write(constrain(t, 0, 180));
  servoDetachAt = millis() + 600;  // detach after the move to stop jitter
}

void laser(bool on, int seconds) {
  if (!on) { digitalWrite(LASER_PIN, LOW); laserOffAt = 0; return; }
  digitalWrite(LASER_PIN, HIGH);
  laserOffAt = millis() + min((unsigned long)seconds * 1000UL, LASER_MAX_MS);
}

void box_led(int index, String colour) {
  strip.clear();
  if (index >= 0 && index < STRIP_LEDS) strip.setPixelColor(index, colourOf(colour, strip));
  strip.show();
  boxOffAt = millis() + 15000;
}

void ring_state(String state) { ringMode = state; ringDirty = true; }

// One solid colour per state, drawn only when the state changes. A redraw every 40 ms (the old
// animation) blocked the Bridge: every call timed out until it was removed. See docs/measurements.md.
void drawRing() {
  if (!ringDirty) return;
  ringDirty = false;
  uint32_t c = ring.Color(0, 10, 40);                                  // idle: dim blue
  if (ringMode == "listening")     c = ring.Color(0, 80, 255);         // bright blue
  else if (ringMode == "thinking") c = ring.Color(140, 75, 0);         // amber
  else if (ringMode == "speaking") c = ring.Color(120, 120, 120);      // white
  else if (ringMode == "error")    c = ring.Color(255, 0, 0);          // red
  ring.fill(c);
  ring.show();
}

void setup() {
  pinMode(LASER_PIN, OUTPUT); digitalWrite(LASER_PIN, LOW);
  strip.begin(); ring.begin(); strip.show(); ring.show();
  Bridge.begin();
  Bridge.provide_safe("point", point);
  Bridge.provide_safe("laser", laser);
  Bridge.provide_safe("box_led", box_led);
  Bridge.provide_safe("ring_state", ring_state);
}

void loop() {
  unsigned long now = millis();
  if (laserOffAt && now >= laserOffAt) { digitalWrite(LASER_PIN, LOW); laserOffAt = 0; }
  if (servoDetachAt && now >= servoDetachAt) { pan.detach(); tilt.detach(); servoDetachAt = 0; }
  if (boxOffAt && now >= boxOffAt) { strip.clear(); strip.show(); boxOffAt = 0; }
  drawRing();
}

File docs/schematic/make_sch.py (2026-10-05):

"""Generates docs/schematic/jarvis.kicad_sch from KiCad 10's stock symbol libraries.

    python docs/schematic/make_sch.py docs/schematic/jarvis.kicad_sch
"""
import re
import sys
import uuid

LIB = "C:/Program Files/KiCad/10.0/share/kicad/symbols/"
OUT = sys.argv[1]
U = lambda: str(uuid.uuid4())
ROOT = U()
INK = "(color 0 0 0 1)"
FRAME = "(color 132 132 132 1)"


# ------------------------------------------------------------------ library access
def sexpr_end(s, i):
    d = 0
    for j in range(i, len(s)):
        d += (s[j] == "(") - (s[j] == ")")
        if d == 0:
            return j + 1


def children(block):
    out, i = [], block.index("(", block.index("(") + 1)
    while i < len(block) - 1:
        if block[i] == "(":
            j = sexpr_end(block, i)
            out.append(block[i:j])
            i = j
        else:
            i += 1
    return out


_src = {}


def lib_symbol(f, name):
    """The symbol block, with 'extends' flattened into a standalone symbol."""
    s = _src.setdefault(f, open(LIB + f, encoding="utf-8").read())
    i = s.index(f'\t(symbol "{name}"\n') + 1
    b = s[i:sexpr_end(s, i)]
    m = re.search(r'\(extends "([^"]+)"\)', b)
    if not m:
        return b
    props = [c for c in children(b) if c.startswith("(property")]
    body = [c.replace(f'(symbol "{m[1]}_', f'(symbol "{name}_') for c in children(lib_symbol(f, m[1]))
            if not c.startswith("(property")]
    return f'(symbol "{name}"\n' + "\n".join(props + body) + ")"


PIN = re.compile(r'\(pin \w+ \w+\s+\(at ([-\d.]+) ([-\d.]+) \d+\).*?\(name "([^"]*)".*?\(number "([^"]*)"', re.S)
libsyms, PINS = [], {}


def use(lib_id, f):
    nm = lib_id.split(":")[1]
    b = lib_symbol(f, nm)
    libsyms.append(b.replace(f'(symbol "{nm}"', f'(symbol "{lib_id}"', 1))
    for sub in re.finditer(r'\(symbol "[^"]+_(\d+)_\d+"', b):
        part = b[sub.start():sexpr_end(b, sub.start())]
        for m in PIN.finditer(part):
            p = PINS.setdefault((lib_id, int(sub[1])), {})
            p[m[4]] = (float(m[1]), float(m[2]))
            p.setdefault(m[3], (float(m[1]), float(m[2])))


for lib_id, f in (("Device:R", "Device.kicad_sym"), ("Device:C", "Device.kicad_sym"),
                  ("Device:C_Polarized", "Device.kicad_sym"), ("Device:D_Laser_1C2A", "Device.kicad_sym"),
                  ("Transistor_FET:IRLZ44N", "Transistor_FET.kicad_sym"),
                  ("MCU_Module:Arduino_UNO_R3", "MCU_Module.kicad_sym"), ("Motor:Motor_Servo", "Motor.kicad_sym"),
                  ("LED:WS2812B", "LED.kicad_sym"), ("74xx:74AHCT125", "74xx.kicad_sym"),
                  ("Connector_Generic:Conn_01x02", "Connector_Generic.kicad_sym"),
                  ("power:+5V", "power.kicad_sym"), ("power:GND", "power.kicad_sym"),
                  ("power:PWR_FLAG", "power.kicad_sym")):
    use(lib_id, f)

# ------------------------------------------------------------------ drawing helpers
items = []


def r2(v):
    return round(v, 2)


def place(lib_id, ref, value, x, y, rot=0, mirror=False, unit=1, ref_at=None, val_at=None, just="left", fa=0):
    """Places a symbol; returns {pin number or name: (x, y)} in sheet coordinates."""
    pos = {}
    for u in (0, unit):
        for k, (px, py) in PINS.get((lib_id, u), {}).items():
            sx, sy = (-px if mirror else px), -py
            for _ in range(rot // 90):  # counter-clockwise on screen
                sx, sy = sy, -sx
            pos[k] = (r2(x + sx), r2(y + sy))
    ref_at = ref_at or (x + 2.54, y - 1.27)
    val_at = val_at or (x + 2.54, y + 1.27)
    j = "" if just == "center" else f"(justify {just})"
    m = "(mirror y) " if mirror else ""
    items.append(f'''(symbol (lib_id "{lib_id}") (at {x} {y} {rot}) {m}(unit {unit}) (exclude_from_sim no) (in_bom yes) (on_board yes) (dnp no) (uuid "{U()}")
  (property "Reference" "{ref}" (at {r2(ref_at[0])} {r2(ref_at[1])} {fa}) (effects (font (size 1.27 1.27)) {j}))
  (property "Value" "{value}" (at {r2(val_at[0])} {r2(val_at[1])} {fa}) (effects (font (size 1.27 1.27)) {j}))
  (property "Footprint" "" (at {x} {y} 0) (hide yes) (effects (font (size 1.27 1.27))))
  (property "Datasheet" "" (at {x} {y} 0) (hide yes) (effects (font (size 1.27 1.27))))
  (instances (project "jarvis" (path "/{ROOT}" (reference "{ref}") (unit {unit})))))''')
    return pos


_pwr = [0]


def pwr(name, p, rot=0):
    """+5V / PWR_FLAG point up and GND points down at rot 0; rot 90 turns +5V to point left."""
    _pwr[0] += 1
    ref = f"#FLG{_pwr[0]:02d}" if name == "PWR_FLAG" else f"#PWR{_pwr[0]:02d}"
    if rot == 90:
        at, j = (p[0] - 3.81, p[1]), "(justify left)"  # rot 90 flips justify
    else:
        at, j = (p[0], p[1] + (3.81 if name == "GND" else -3.81)), ""
    items.append(f'''(symbol (lib_id "power:{name}") (at {p[0]} {p[1]} {rot}) (unit 1) (exclude_from_sim no) (in_bom yes) (on_board yes) (dnp no) (uuid "{U()}")
  (property "Reference" "{ref}" (at {p[0]} {p[1]} 0) (hide yes) (effects (font (size 1.27 1.27))))
  (property "Value" "{name}" (at {r2(at[0])} {r2(at[1])} {rot}) (effects (font (size 1.27 1.27)) {j}))
  (property "Footprint" "" (at 0 0 0) (hide yes) (effects (font (size 1.27 1.27))))
  (property "Datasheet" "" (at 0 0 0) (hide yes) (effects (font (size 1.27 1.27))))
  (instances (project "jarvis" (path "/{ROOT}" (reference "{ref}") (unit 1)))))''')


def wire(*pts):
    """Wire through the points; a diagonal step becomes horizontal-then-vertical."""
    for a, b in zip(pts, pts[1:]):
        if a[0] != b[0] and a[1] != b[1]:
            c = (b[0], a[1])
            items.append(f'(wire (pts (xy {a[0]} {a[1]}) (xy {c[0]} {c[1]})) (stroke (width 0) (type default)) (uuid "{U()}"))')
            a = c
        items.append(f'(wire (pts (xy {a[0]} {a[1]}) (xy {b[0]} {b[1]})) (stroke (width 0) (type default)) (uuid "{U()}"))')


def dot(p):
    items.append(f'(junction (at {p[0]} {p[1]}) (diameter 0) (color 0 0 0 0) (uuid "{U()}"))')


def nc(p):
    items.append(f'(no_connect (at {p[0]} {p[1]}) (uuid "{U()}"))')


def glabel(name, p, shape, left=False):
    """Global label whose connection point is p; the flag extends right, or left with left=True."""
    rot, j = (180, "right") if left else (0, "left")
    items.append(f'(global_label "{name}" (shape {shape}) (at {p[0]} {p[1]} {rot}) (fields_autoplaced yes) '
                 f'(effects (font (size 1.27 1.27)) (justify {j})) (uuid "{U()}"))')


def text(s, x, y, size=1.27, bold=False, just="left"):
    b = " (bold yes)" if bold else ""
    j = "" if just == "center" else f" (justify {just} bottom)"
    items.append(f'(text "{s}" (exclude_from_sim no) (at {x} {y} 0) (effects (font (size {size} {size}){b} {INK}){j}) (uuid "{U()}"))')


def line(*pts, dash=False):
    xy = " ".join(f"(xy {x} {y})" for x, y in pts)
    t = "dash" if dash else "solid"
    items.append(f'(polyline (pts {xy}) (stroke (width 0.2) (type {t}) {INK}) (uuid "{U()}"))')
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

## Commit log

2026-10-04 JARVIS: offline lab voice assistant for the Arduino UNO Q
    App Lab app (Gemma 3 1B via the llama.cpp brick, whisper tiny.en, Piper)
    with a keyword-first parser that falls back to Gemma, code-side validation,
    SQLite loan log with spoken confirmation, STM32 sketch for the laser turret,
    box LEDs and status ring, dashboard, 25 tests, 60-command evaluation and
    on-board measurements.
2026-10-04 Bluetooth speaker, follow-up questions and small talk, polished replies
    Speak through a Bluetooth speaker when no USB one is plugged in, ask
    "Anything else?" after each answer and end on thanks/no, answer short
    small talk in code, rewrite the persona lines, switch to the northern
    English Piper voice. Log the spoken runs (measurements section 10) and
    the Bluetooth setup in the tutorial.
2026-10-04 Stop recording on silence, strip the wake word, mic watcher
    Record until the speaker pauses (6 s max) instead of a fixed 5 s, drop
    "Hey Arduino" from transcripts so it can't match the Arduino Uno, lower
    the output peak for the Bluetooth speaker, and add tools/mic-watch.sh to
    recover the mic after a USB replug. Document start-on-boot.
2026-10-04 Camera tool finder: template matching plus laser-dot calibration
    The camera looks for the tool on the wall (OpenCV template match, no
    training) and the laser points where it actually is. A sweep that
    watches the laser dot maps pixel x to pan angle, clamped to the range
    where the dot was seen. Moved tools are reported near the closest hook,
    missing ones are never pointed at, and without a camera, template or
    calibration the home hook is used as before.
2026-10-05 Slower voice, one speech at a time, Bluetooth re-pair watcher, servo test endpoint
    - Piper length_scale 1.3: replies were too fast to follow on the Bluetooth speaker
    - Lock around speak() so the dashboard and the voice loop cannot talk over each other
    - mic-watch.sh reconnects the speaker every minute and re-pairs it with pairable on
    (it was paired but never bonded, so the key was lost on every reboot)
    - POST /api/point?pan= moves the pan servo only, for bench tests
2026-10-05 Real hook angles, tool-for-task matching, asking for the job, laser on D3
    - Hooks jogged by eye on the bench wall: stripper 50, vernier 65, multimeter 79 (one servo, up/down)
    - Vernier caliper added; seed() now syncs hooks and items on every start, keeping loans
    - Keyword rules pick a tool by matching the job to its listed uses (baseline 41/60 -> 47/60)
    - "I have this need" / "which tool should I use?" asks for the job, then points at the tool
    - Calibration picks the image axis the laser dot moved along (sideways or up/down)
    - Laser moved to D3
    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
2026-10-05 Hey Jarvis wake word, faster replies, laser timed to the reply
    - Use the Edge Impulse "Hey Jarvis" model (label JARVIS) via the keyword
    spotting brick's EI_KEYWORD_SPOTTING_MODEL variable; the .eim stays out of git
    - A bare wake word (or whisper's "Hey Elvis") gets "Yes, sir?" and never
    reaches the model; the wake word is stripped anywhere in the sentence
    - Ignore wakes while JARVIS is talking or within 1.5 s after
    - Speak sentence by sentence with the next one synthesised during playback,
    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
2026-10-05 Two-servo pan-tilt head with camera aiming, laser on D7, KiCad schematic
    - Hooks store (pan, tilt); the camera fit maps where it sees a tool to both
    angles and clamps the aim to the area the calibrated hooks cover
    - /api/point jogs pan and tilt and can light the laser (still off after 10 s)
    - Laser moved from D3 to D7; board FQBN added to the sketch profile
    - KiCad schematic in docs/schematic: source, PDF and the script that generates it
    - Tests updated for the two-axis fit (35 pass); README and tutorial updated
    [jarvis.kicad_sch]
2026-10-05 Wiring guide for the pan-tilt head; edit on README
    - wiring.md: two-servo pan-tilt build steps, laser on D7 with the MOSFET and
    resistor values, two-step hook calibration (jog angles, then camera fit),
    link to the schematic
    - edit on README
2026-10-05 README: note the last update time and the added schematic
